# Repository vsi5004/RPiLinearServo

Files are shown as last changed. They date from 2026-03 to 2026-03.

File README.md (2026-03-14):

# RPiLinearServo

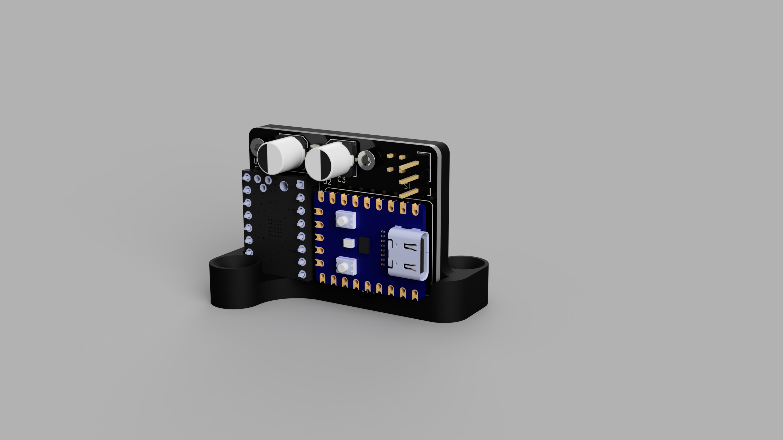
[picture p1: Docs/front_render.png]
RPiLinearServo


A closed-loop linear servo based on the RP2040, using a micro stepper linear actuator with an 8.5 mm throw and a BTT v1.3 TMC2209 driver. Designed as an RC servo replacement / turnout actuator for model railroads that allows for smooth and reliable slow speed operation and ease of configuration for a wide range of applications.

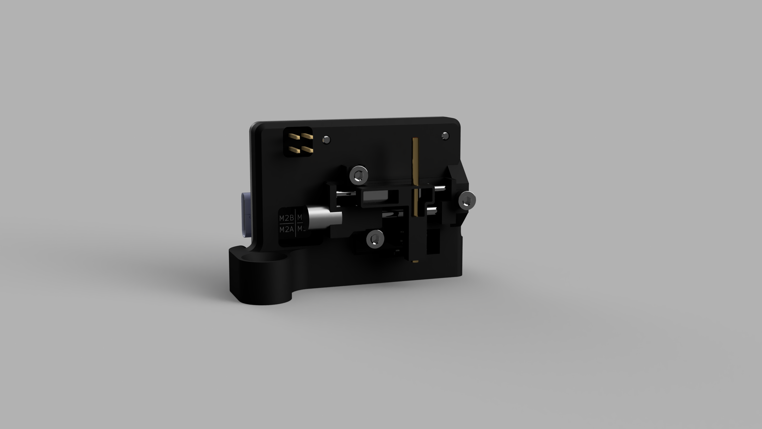
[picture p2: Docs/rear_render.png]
RPiLinearServo rear


## Features

- Controllable via standard servo PWM signal allowing for plug-and-play integration in systems designed for miniature R/C servos
- Easy firmware updates - just drag and drop compiled binary into mounted drive to flash
- Widely configurable by editing a `CONFIG.INI` file when device is connected as a usb drive to allow for adaptation to wide range of use cases
- Smooth, quiet, controllable, and repeatable motion not available in smaller servos
- Non-backdrivable lead screw linear stage can be powered off in a low power state while not in use
- Automatic homing routine runs once and is then stored and persists throughout the life of the device
- Closed loop magnetic feedback allows for seamless, accurate adjustments if external factors cause motor to miss steps
- Interactive USB CLI (via serial monitor) exposes full command set for motion control, diagnostics, and debugging

## Hardware

| Component | Details |
|---|---|
| MCU | Waveshare RP2040-Zero |
| Driver | BTT TMC2209 v1.3 SilentStepStick |
| Actuator | Micro stepper linear slide, 8.4 mm travel (~208.3 full steps/mm) |
| Hall Sensor | TI DRV5055 A2 (optional, for closed-loop verification) |

See the [PCB README](PCB/README.md) for the full schematic, BOM, and GPIO assignments.

## Getting Started

### Flash the firmware

1. Hold **BOOTSEL** on the RP2040-Zero and plug in USB.
2. Drag `RPiLinearServo.uf2` onto the **RPI-RP2** drive.
3. The board reboots and enumerates as a composite USB device (CDC serial + MSC config drive).

Pre-built `.uf2` files are available on the [Releases](../../releases) page — or build from source (see the [Firmware README](Firmware/RPiLinearServo/README.md)).

### Connect a PWM signal

Wire a standard RC servo signal (1000–2000 µs) to GP0. On the first valid pulse the servo automatically homes (drives into the hardstop, backs off, and zeroes) then begins tracking the PWM target.

If the PWM signal is lost for more than 100 ms (configurable), the motor is disabled and the LED enters an idle heartbeat.

### Configure via USB drive

The device mounts a small USB drive named **LINEARSERVO** containing `CONFIG.INI`. Edit with any text editor, save, and **safely eject**. The firmware applies changes within ~500 ms.

```ini
[stroke]
stroke_mm = 8.40
full_steps_per_mm = 208.3

[driver]
dir_invert = false
run_current_ma = 100
hold_current_ma = 50

[motion]
default_speed_mm_s = 40.0
max_accel_mm_s2 = 80.0
auto_disable_ms = 2000

[rc_pwm]
min_us = 1000
max_us = 2000

[led]
dark_mode = false

[power]
sleep_when_idle = false

[sensor]
use_hall_effect = false
```

### USB CLI

Connect a serial terminal (PuTTY, minicom, `screen /dev/ttyACM0 115200`) to the CDC port. The CLI is always active alongside PWM control.

```
> help
Commands:
  move <steps> [speed_hz]  Move relative steps (negative = reverse)
  run [speed_hz]           Continuous stepping
  stop                     Stop immediately
  home                     Run homing sequence
  enable                   Enable motor driver
  disable                  Disable motor driver
  dir <fwd|rev>            Set direction for 'run'
  speed <hz>               Set default speed
  pos                      Print position
  status                   Print full status
  pwm                      Print PWM input status
  nvm                      Print/save position state
  hall                     Hall sensor reading
  hallcal                  Dump hall calibration table
  faultclr                 Clear stall fault
  help                     This message
```

CLI commands go through the same servo loop state machine as PWM-driven moves, so LED and driver enable behaviour is always consistent.

## Project Structure

| Directory | Description | Details |
|---|---|---|
| [Firmware/RPiLinearServo](Firmware/RPiLinearServo/README.md) | RP2040 firmware (C++17, Pico SDK) | Build instructions, architecture, module reference |
| [PCB](PCB/README.md) | KiCad 8 schematic & PCB | BOM, GPIO map, sourcing notes, Gerber outputs |
| [Mechanical](Mechanical/README.md) | 3D-printable mounting hardware | Mount variants, print settings, additional parts |
| [Docs](Docs/) | Renders and specifications | Project renders, design spec |

## License

This project is licensed under the [MIT License](LICENSE).

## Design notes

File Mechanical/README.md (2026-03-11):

# Mechanical — RPiLinearServo

3D-printable mounting hardware for the RPiLinearServo assembly. Multiple base variants are included to suit different installation orientations.

## Mount Variants

| File | Description |
|---|---|
| `Base - Vertical.3mf` | Standard vertical mount — actuator perpendicular to the mounting surface |
| `Base - Vertical (Long Screws).3mf` | Vertical mount variant with taller screw bosses for longer fasteners |
| `Base - Horizontal Left.3mf` | Horizontal mount — actuator parallel to the mounting surface, offset left |
| `Actuator Horn.3mf` | Output horn that attaches to the actuator slider |

The vertical mounts are intended for under-baseboard turnout installations where the actuator pushes/pulls a wire or rod through the surface. The horizontal mount is for side-mounting applications where the actuator drives a linkage parallel to the mounting plane.

## Print Settings

These parts are designed for FDM printing with standard settings:

| Parameter | Recommended |
|---|---|
| Layer height | 0.2 mm |
| Infill | 20–30 % |
| Material | PLA or PETG |
| Supports | Not required |
| Walls / perimeters | 3–4 |
| Top / bottom layers | 4–5 |

### Orientation

- **Base variants** — print flat on the mounting face (as oriented in the 3MF files). No supports needed.
- **Actuator horn** — print flat. The connection features are designed to print cleanly without supports.

## Additional Parts and Materials

Beyond the 3D-printed parts and the PCB assembly, you will need:

| Item | Qty | Notes |
|---|---|---|
| Micro stepper linear actuator (8.4 mm throw) | 1 | The actuator the PCB is designed around |
| M2 or M2.5 screws | 2–4 | For mounting the base to your surface (length depends on variant) |
| M2 screws (short) | 2 | For securing the PCB to the base mount |
| Hookup wire | — | For PWM signal and power connections |
| JB Weld Pro Cold Weld Epoxy| - | Used for fixing actuator horn to linear slide |
| 1.5mm OD x 1.0 ID x 20mm brass tubing | 1 | Acts as a bushing for pushrod | 
| Piano wire or control rod | 1 | For turnout linkage (vertical mount applications) |

## Assembly

1. Secure the PCB to the printed base using M2 screws.
2. Connect the stepper actuator to the J2 motor header.
3. Route the PWM signal wire and power leads.
4. If using a vertical mount for turnout control, run a piano wire or control rod through the horn and the baseboard to the tie bar.
5. Mount the assembly under the baseboard with M2/M2.5 screws.

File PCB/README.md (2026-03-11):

# PCB — RPiLinearServo

KiCad schematic and PCB design files for the RPiLinearServo controller board.

## GPIO Assignments

| Signal | RP2040-Zero | TMC2209 Pin | Notes |
|---|---|---|---|
| PWM input | GP0 | — | RC servo signal via PIO1/SM1 |
| nENABLE | GP1 | EN | Active-low driver enable |
| STEP | GP2 | STEP | PIO0/SM0 driven |
| DIR | GP3 | DIR | GPIO |
| UART TX | GP4 | PDN/UART | Via 1 kΩ series resistor on PCB |
| UART RX | GP5 | PDN/UART | Loopback on bus |
| INDEX | GP7 | INDEX | Unused (reserved) |
| DIAG | GP9 | DIAG | Unused (reserved) |
| LED | GP16 | — | WS2812 RGB via PIO1/SM0 |
| Hall sensor | GP26 | — | DRV5055 A2 analog via ADC0 |

### UART bus isolation

The 1 kΩ series resistor (R1) between GP4 and the TMC2209 PDN/UART pin provides signal isolation so the driver can pull the bus low during reply frames without fighting the RP2040 TX output. GP4 is tri-stated after each write to allow the TMC2209 to respond over the half-duplex bus.

### PWM input protection

The PWM input on GP0 is routed through a 74LVC1G17 Schmitt-trigger buffer (U4) for signal conditioning. A TPD1E10B06DPYR ESD protection diode (D1) clamps the input to protect against transient voltage spikes from the RC servo signal line.

## Bill of Materials

| Ref | Part | Value / Description | Package | Qty |
|---|---|---|---|---|
| U2 | Waveshare RP2040-Zero | Dual-core RP2040 MCU module | Through-hole module | 1 |
| U1 | BTT TMC2209 v1.3 SilentStepStick | Stepper driver with UART | Through-hole module | 1 |
| U3 | TI DRV5055A2xDBZxQ1 | Ratiometric linear hall-effect sensor, 25 mV/mT | SOT-23 | 1 |
| U4 | 74LVC1G17 | Single Schmitt-trigger buffer | SOT-23-5 | 1 |
| D1 | TI TPD1E10B06DPYR | ESD protection diode, ±30 kV HBM | 0402 | 1 |
| C1, C3 | Panasonic EEEFPC101XAP | 100 µF 16 V aluminum electrolytic | Radial (custom footprint) | 2 |
| C2, C5 | Ceramic | 2.2 µF | 0805 | 2 |
| C4, C6 | Ceramic | 0.1 µF (decoupling) | 0402 | 2 |
| R1, R2 | Resistor | 1 kΩ | 0603 | 2 |
| R3 | Resistor | 330 Ω | 0603 | 1 |
| J1 | Pin header 1×3 | Hall sensor / PWM input connector | 2.54 mm pitch | 1 |
| J2 | Pin header 2×2 (omit, used for pads only)| Stepper motor phase connector | 2.54 mm pitch | 1 |

### Sourcing notes

| Part | Suggested source |
|---|---|
| Waveshare RP2040-Zero | [Waveshare](https://www.waveshare.com/rp2040-zero.htm), AliExpress, Amazon |
| BTT TMC2209 v1.3 SilentStepStick | [BIGTREETECH](https://biqu.equipment/products/bigtreetech-tmc2209-stepper-motor-driver-for-3d-printer-board-vs-tmc2208), Amazon, AliExpress |
| TI DRV5055A2xDBZxQ1 | DigiKey, Mouser, LCSC |
| 74LVC1G17 | DigiKey, Mouser, LCSC |
| TPD1E10B06DPYR | DigiKey (296-30406-1-ND), Mouser |
| Panasonic EEEFPC101XAP | DigiKey (PCE4534CT-ND), Mouser |
| Passives (0402/0603/0805) | LCSC, DigiKey, Mouser |

All SMD passives use hand-solder footprints with extended pads for easier assembly.

## Design Files

| Path | Description |
|---|---|
| `RPiLinearServo.kicad_sch` | Schematic |
| `RPiLinearServo.kicad_pcb` | PCB layout |
| `RPiLinearServo.kicad_pro` | KiCad project |
| `RPiLinearServo.step` | 3D model of assembled board |
| `Components/` | Custom KiCad symbol libraries + 3D STEP models |
| `CustomFootprints/` | Custom KiCad footprint libraries |

## Manufacturing Outputs

Pre-generated Gerber and drill files are in `Outputs/`:

| File | Description |
|---|---|
| `*-F_Cu.gbr`, `*-B_Cu.gbr` | Front/back copper |
| `*-F_Mask.gbr`, `*-B_Mask.gbr` | Front/back solder mask |
| `*-F_Paste.gbr`, `*-B_Paste.gbr` | Front/back paste stencil |
| `*-F_Silkscreen.gbr`, `*-B_Silkscreen.gbr` | Front/back silkscreen |
| `*-Edge_Cuts.gbr` | Board outline |
| `*-PTH.drl`, `*-NPTH.drl` | Plated / non-plated drill files |
| `*-top-pos.csv`, `*-bottom-pos.csv` | Pick-and-place position files |
| `*-BOM.csv` | Bill of materials (semicolon-delimited) |
| `*-job.gbrjob` | Gerber job file |

These files are ready to upload directly to PCB fabricators such as JLCPCB, PCBWay, or OSH Park.

### PCB specifications

| Parameter | Value |
|---|---|
| Minimum trace width | 0.2 mm |
| Default trace width | 0.2 mm |
| Via diameter / drill | 0.6 mm / 0.3 mm |
| Copper-to-edge clearance | 0.4 mm |
| Layers | 2 |

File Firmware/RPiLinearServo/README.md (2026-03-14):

# Firmware — RPiLinearServo

C++17 firmware for the RP2040-Zero targeting the Pico SDK. Implements closed-loop stepper control, RC PWM tracking, USB configuration, and interactive CLI.

## Build

### Prerequisites

- [Pico SDK](https://github.com/raspberrypi/pico-sdk) v2.2.0 — set `PICO_SDK_PATH` environment variable
- ARM GCC toolchain (14.2 Rel1 or compatible)
- CMake ≥ 3.13
- Ninja (or Make)

### Build from source

```bash
cd Firmware/RPiLinearServo
mkdir -p build && cd build
cmake ..
ninja
```

This produces `RPiLinearServo.uf2` along with `.bin`, `.hex`, `.dis` (disassembly), and `.map` (symbol map) outputs.

### Flash

1. Hold **BOOTSEL** on the RP2040-Zero and plug in USB.
2. Drag `RPiLinearServo.uf2` onto the **RPI-RP2** drive.
3. The board reboots and enumerates as a composite USB device (CDC serial + MSC config drive).

Alternatively, use the **Run Project** task in VS Code to build and flash in one step.

### VS Code development

The project includes CMake presets and VS Code tasks for a streamlined workflow:

1. Set `PICO_SDK_PATH` in your environment (or in `.vscode/settings.json`).
2. Open the `Firmware/RPiLinearServo` folder in VS Code.
3. CMake Tools will auto-configure the build directory.
4. Use **Build** (Ctrl+Shift+B) and **Run Project** tasks.

## Architecture

### Main loop

The firmware runs a single-core bare-metal event loop (`main.cpp`). There is no RTOS — all work is cooperative:

```
main loop
  ├── cli_poll()                  USB command processing (non-blocking)
  ├── msc_disk_poll()             Detect CONFIG.INI writes → apply settings
  ├── servo_loop_poll()           Servo state machine (see below)
  ├── status_led_update()         WS2812 LED animation state machine
  └── position_save_if_needed()   Throttled NVM write (≤ once per 30 s)
```

### Servo loop state machine (`motion/servo_loop.cpp`)

All motor control — whether initiated by PWM input or the USB CLI — flows through a single state machine.  This guarantees that the driver enable pin, LED status, and idle timeout are always consistent regardless of the command source.

```
  ┌──────┐   first valid PWM   ┌────────┐  blocking   ┌─────────┐
  │ IDLE │ ─────────────────► │ HOMING │ ──────────► │ HOLDING │
  └──┬───┘                     └────────┘             └────┬────┘
     │  move cmd / PWM error                               │
     │  ┌────────┐  move complete   ┌─────────┐            │
     └►│ MOVING │ ────────────────►│ HOLDING │◄───────────┘
       └────────┘                   └────┬────┘
                                         │ auto_disable_ms timeout
                                         │ or PWM signal lost
                                         ▼
                                      ┌──────┐
                                      │ IDLE │
                                      └──────┘
```

**States:**

| State | EN pin | LED | Description |
|---|---|---|---|
| IDLE | Disabled | Amber breathing | Motor off, waiting for input or dormant entry |
| HOMING | Enabled | Blue breathing | Blocking hardstop homing in progress |
| MOVING | Enabled | Solid blue | Stepgen actively running toward a target |
| HOLDING | Enabled | Solid green | At target, idle timer counting toward auto-disable |

Transitions are evaluated once per poll in a single `switch` block.  The `enter_state()` helper is the **only** place that touches the EN pin or LED status, eliminating any possibility of EN/LED desynchronisation.

**Public API** (used by both CLI and PWM tracking):

| Function | Description |
|---|---|
| `servo_loop_move(steps, speed, accel)` | Start an accelerated finite move |
| `servo_loop_run(speed)` | Start continuous stepping |
| `servo_loop_stop()` | Stop and enter HOLDING |
| `servo_loop_enable()` | Enable driver (IDLE → HOLDING) |
| `servo_loop_disable()` | Disable driver (any → IDLE) |
| `servo_loop_home()` | Run blocking homing sequence |

### Interrupt / real-time layer

| Source | Handler | Purpose |
|---|---|---|
| PIO0 IRQ0 | Step counter ISR | Increment/decrement position on every STEP rising edge |
| 1 kHz repeating timer | Accel/decel ISR | Update PIO clock divider for trapezoidal speed profile |
| PIO1 RX FIFO | PWM capture | New pulse width measurement available |

## Modules

### Step Generation (`drivers/stepgen/`)

PIO0/SM0 runs a 4-cycle program that generates a square wave on the STEP pin and fires IRQ0 on each rising edge. The CPU IRQ handler maintains an exact position counter (no drift).

Speed is controlled by adjusting the PIO state machine clock divider:

$$f_{step} = \frac{f_{clk\_sys}}{4 \times clk\_div}$$

Key functions:
- `stepgen_move(steps, speed_hz)` — move exactly N steps at constant speed
- `stepgen_move_accel(steps, max_hz, accel_hz_per_s)` — trapezoidal acceleration profile via 1 kHz timer
- `stepgen_run(speed_hz)` — continuous stepping
- `stepgen_get_position()` — read current step count

### TMC2209 Driver (`drivers/tmc2209/`)

Communicates over hardware UART1 (115200 baud, 8N1) on a half-duplex single-wire bus. Reads and writes TMC2209 registers with CRC8 validation. The TX pin is tri-stated after each write to allow the driver to reply.

At startup the firmware writes the following registers:

| Parameter | Default | Description |
|---|---|---|
| `run_current_ma` | 100 | RMS run current (mA) |
| `hold_current_ma` | 50 | RMS hold current (mA) |
| `microsteps` | 8 | Microstepping divisor |
| `stealthchop_en` | true | StealthChop (quiet) mode |
| `tpowerdown` | 46 | ~1 s IRUN → IHOLD ramp |

- `GCONF = 0x1C0` — full software current control, PDN disabled, register-select microstepping, multistep filter.
- `CHOPCONF` — only MRES and interpolation bits are modified; OTP defaults for TBL / HSTRT / HEND are preserved.

All parameters are runtime-configurable via the USB config drive (`CONFIG.INI`).

### PWM Input (`drivers/pwm_input/`)

PIO1/SM1 measures the HIGH time of an RC servo pulse at 16 ns resolution (125 MHz system clock). Valid range is configurable (default 1000–2000 µs). A timeout fires if no valid pulse is received within `pwm_timeout_ms`.

### Hall Sensor (`drivers/hall_sensor/`)

Reads the DRV5055 analog output on ADC0 (GP26) with 64× oversampling across 5 accumulated reads per update. An optional EMA filter smooths the signal. Used for:
- Stall detection during homing (voltage derivative monitoring)
- Post-move position verification via 128-entry calibration LUT
- Lost-step correction (single attempt, then fault if still out of tolerance)

### Dormant Sleep (`power/dormant.cpp`)

When `sleep_when_idle` is enabled and the PWM signal is lost, the RP2040 enters XOSC dormant mode — halting the crystal oscillator and both PLLs for minimal power draw. The device wakes instantly on the next PWM rising edge (GP0).

Entry conditions (all must be true):
- `sleep_when_idle = true` in config
- PWM signal timed out and motor auto-disabled **or** no valid pulse received within 5 seconds of boot
- USB host not mounted (prevents sleeping while CLI / config drive is in use)

Pre-sleep sequence: force an unconditional position save to flash, stash position in RAM, disable motor and LED, disable all PIO state machines, clear PIO instruction memory, switch clocks to XOSC, shut down both PLLs.

Post-wake sequence: restore PLLs and system clock, re-initialise all peripherals (USB, TMC2209, PIO drivers, hall sensor), restore position from RAM (avoids stale-flash mismatches), re-init the servo loop.

### Servo Loop (`motion/`)

The top-level motion coordinator.  An explicit state machine (IDLE → HOMING → MOVING → HOLDING) polled from the main loop.  All motor commands — from both the USB CLI and PWM tracking — flow through the same `servo_loop_*` API, ensuring EN pin, LED, and timeout state are always consistent.

Key behaviours:
- **PWM tracking** — maps pulse width to a target position, applies deadband, and commands moves with acceleration
- **Auto-home** — triggers homing on the first valid PWM pulse if not already homed
- **Post-move verification** — after each move settles, compares the hall sensor reading against the calibration LUT and attempts a single correction if a mismatch is detected
- **Auto-disable** — disables the driver after `auto_disable_ms` of idle time (HOLDING → IDLE)
- **PWM signal loss** — if the PWM signal drops during a move, the servo transitions directly from MOVING to IDLE on completion rather than lingering in HOLDING

### Homing (`motion/homing.cpp`)

Hardstop homing sequence:

1. Drive `home_margin × stroke` steps into the end-stop at `home_speed_mm_s`
2. Monitor hall sensor: stall detected when voltage derivative falls below threshold for 5 consecutive samples (after 20% of stroke has been commanded)
3. Back off by `backoff_mm` with acceleration
4. Calibration sweep: slow pass across full stroke to build 128-entry V-curve LUT
5. Reset position to 0, save LUT to flash

### USB (`usb/`)

Composite TinyUSB device with two interfaces:

- **CDC** — USB serial port for the interactive CLI
- **MSC** — virtual FAT12 mass storage drive (8 KB RAMdisk) exposing `CONFIG.INI`

The MSC driver detects write completions with a 500 ms idle timeout, then parses the INI, validates ranges, saves to flash, and re-applies driver settings.

### Storage (`storage/`)

All persistent data lives in dedicated 4 KB sectors at the end of the 2 MB flash:

| Offset | Purpose | Protection |
|---|---|---|
| `0x1F0000` | Position slot A | CRC32, dual-slot wear leveling |
| `0x1F1000` | Position slot B | CRC32, dual-slot wear leveling |
| `0x1F2000` | ServoConfig | CRC32, magic + version |
| `0x1F3000` | Hall calibration LUT | CRC32, magic + version |

Position saves are throttled to once every 30 seconds to protect flash endurance. An immediate save occurs after homing.

### Status LED (`ui/status_led.cpp`)

WS2812 state machine with the following visual states:

| State | Pattern |
|---|---|
| OFF | Dark (dark mode enabled) |
| IDLE | Amber breathing pulse (~5 s period) |
| HOLDING | Solid green |
| MOVING | Solid blue |
| HOMING | Breathing blue (500 ms cycle) |
| HOMING_DONE | 3× green flash → HOLDING |
| STALL_FAULT | Rapid red flash |
| ERROR | Solid red |

## Configuration Reference

The `ServoConfig` struct (`include/config.h`) contains all runtime parameters. Defaults are compiled in and can be overridden via the USB config drive or flash persistence.

| Section | Parameter | Default | Description |
|---|---|---|---|
| Stroke | `stroke_mm` | 8.40 | Actuator travel (mm) |
| | `full_steps_per_mm` | 208.3 | Motor full steps per mm |
| Driver | `dir_invert` | false | Invert direction pin |
| | `run_current_ma` | 100 | RMS run current (mA) |
| | `hold_current_ma` | 50 | RMS hold current (mA) |
| | `microsteps` | 8 | Microstepping divisor |
| | `stealthchop_en` | true | StealthChop mode |
| Motion | `default_speed_mm_s` | 40.0 | Default move speed (mm/s) |
| | `max_accel_mm_s2` | 80.0 | Acceleration limit (mm/s²) |
| | `auto_disable_ms` | 2000 | Idle timeout before disabling driver (0 = never) |
| RC PWM | `pwm_min_us` | 1000 | Minimum valid pulse width (µs) |
| | `pwm_max_us` | 2000 | Maximum valid pulse width (µs) |
| | `pwm_timeout_ms` | 100 | Signal-lost timeout (ms) |
| LED | `dark_mode` | false | Disable status LED |
| Power | `sleep_when_idle` | false | Enter dormant mode when PWM signal is lost (wake on next pulse) |
| Sensor | `use_hall_effect` | false | Enable hall sensor feedback |

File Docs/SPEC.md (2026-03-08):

# SPEC.md  
RP2040 Linear Servo Firmware Specification  
Target Board: Waveshare RP2040-Zero  

---

## 0. Overview

This firmware implements a closed-loop "linear servo" using an RP2040 and a linear stepper actuator. The device behaves like an RC servo replacement and optionally a turnout actuator.

Features:

- RC PWM input (standard servo pulse)
- Closed-loop position control using linear Hall sensor
- Automatic homing against mechanical stop
- USB Mass Storage (MSC) runtime configuration drive
- INI-based configuration file (`CONFIG.INI`)
- Persistent position and calibration storage in flash
- UF2 firmware update via BOOTSEL
- Optional USB CDC logging

Primary development stack: Pico SDK (C/C++) + TinyUSB.

---

## 1. Hardware Assumptions

### 1.1 MCU
- RP2040
- 2MB external QSPI flash
- USB device mode

### 1.2 Motor Driver

TMC2209 SilentStepStick

Interface:
- STEP / DIR / EN (STEP/DIR class — same as DRV8825)
- Single-wire UART for startup configuration (current, microstepping, StealthChop, StallGuard)
- DIAG output for StallGuard2 stall detection

GPIO assignments (Waveshare RP2040-Zero):

| Signal | GPIO | Direction | Notes |
|---|---|---|---|
| nENABLE | GP1 | OUT | Active-low |
| STEP | GP2 | OUT | PIO state machine (PIO0) |
| DIR | GP3 | OUT | GPIO |
| UART TX | GP4 | OUT | To TMC2209 PDN/UART via 1K R1 on PCB; also UART1_TX |
| UART RX | GP5 | IN | Loopback on same UART bus; also UART1_RX |
| DIAG | GP7 | IN | StallGuard2 output (high = stall detected) |
| INDEX | GP9 | IN | TMC2209 step pulse output (future use) |
| PWM input | GP0 | IN | RC servo signal |
| Hall sensor | GP26 | IN | Analog (ADC0) |

The UART is implemented with hardware UART1 (GP4=UART1_TX, GP5=UART1_RX) at 115200 baud 8N1. This leaves both PIO0 and PIO1 available for step generation, PWM capture and other future use.

### 1.3 Sensors
- Linear analog Hall sensor (e.g., A1302)
- Analog speed potentiometer
- RC PWM input

### 1.4 Mechanical
- Linear stepper actuator
- Non-backdrivable
- Hard end stop safe for stall homing

---

## 2. Functional Requirements

### 2.1 PWM Input

Standard RC servo PWM:
- 50Hz nominal
- 1000–2000 microseconds typical

Mapping:

```
pos_mm = (pulse_us - min_us) * stroke_mm / (max_us - min_us)
```

Clamped to [0, stroke_mm].

Configuration parameters:
- `min_us`
- `max_us`
- `timeout_ms`
- `pwm_zero_disables`
- `valid_margin_us`

Behavior:
- If no valid pulse for `timeout_ms`, PWM considered absent.
- If `pwm_zero_disables=true`, disable motor driver.
- Resume when valid PWM returns.
- If not homed and valid PWM appears → run homing first.

PWM capture must use PIO for deterministic measurement.

---

### 2.2 Homing

Triggered if:
- `homed=false`
- valid PWM received

Two homing modes (selected by `use_stallguard` config flag):

#### StallGuard homing (preferred, `use_stallguard = true`)

1. Configure TMC2209 StallGuard threshold via UART (`SGTHRS` register).
2. Move toward home direction at `home_speed_mm_s`.
3. Poll DIAG pin (GP7). When TMC2209 detects stall, DIAG goes high.
4. Call `stepgen_stop()` immediately — motor stops at contact point.
5. Back off by `backoff_mm`.
6. Set logical zero position.
7. Persist `homed=true`.

StallGuard is only active when the step rate exceeds `TCOOLTHRS` (set to maximum in firmware). Threshold tuning: increase `sg_threshold` if false triggers during normal motion; decrease if stall is not detected.

#### Time-based homing (fallback, `use_stallguard = false`)

1. Move toward home direction at `home_speed_mm_s`.
2. Drive 120% of stroke — motor stalls but PIO continues generating pulses.
3. Wait for step count to exhaust (all pulses issued).
4. Back off by `backoff_mm`.
5. Set logical zero position.

#### Hall latch (future)

When `use_latch = true`:
- After initial stall stop, approach slowly at `latch_speed_mm_s`
- Use Hall sensor position as zero reference

---

### 2.3 Closed Loop Control

Control loop frequency: 200–1000 Hz.

Inputs:
- Target position (from PWM)
- Current position (from Hall sensor)

Motion limits:
- `max_speed_mm_s`
- `min_speed_mm_s`
- `max_accel_mm_s2`
- `deadband_mm`

Speed potentiometer scales max speed:

```
effective_max_speed = min_speed + pot_norm * (max_speed - min_speed)
```

Stop stepping when error < deadband.

---

### 2.4 Disable Behavior

If PWM absent and `pwm_zero_disables=true`:
- Disable driver (EN pin)
- Stop control loop motion
- Assume position holds (non-backdrivable)

Persist position with throttling.

---

### 2.5 Boot Position Recovery

On boot:
- Load `homed` and `last_position_mm`
- Read Hall sensor

If mismatch > `pos_mismatch_mm`, trust Hall reading.

If not homed:
- Require homing before motion.

---

### 2.6 Nonvolatile Storage

Persist:
- `homed`
- `last_position_mm`
- Last-good config checksum
- Calibration data

Flash requirements:
- CRC protected
- Versioned struct
- A/B slot or ring buffer

Write throttling:
- Save only when disabled OR
- Every `pos_save_interval_s`
- Never more often than `min_save_interval_s`

---

## 3. USB Mass Storage Configuration Drive

### 3.1 USB Classes

- Required: MSC
- Recommended: MSC + CDC composite

### 3.2 Volume Layout

Volume label: `LINEARSERVO`

Files:
- `CONFIG.INI` (R/W)
- `STATUS.TXT` (RO)
- `README.TXT` (optional)

Disk size: 128–256 KB FAT volume
Backed by reserved flash region.

---

### 3.3 Config Apply Logic

On MSC write:
- Track if CONFIG.INI sectors modified.
- After `config_apply_idle_ms` (e.g. 500ms no writes):
  - Parse CONFIG.INI
  - If valid:
    - Apply
    - Persist as last-good
  - If invalid:
    - Reject
    - Write error to STATUS.TXT

---

## 4. CONFIG.INI Schema

Example:

```
[meta]
version = 1

[rc_pwm]
min_us = 1000
max_us = 2000
timeout_ms = 100
pwm_zero_disables = true
valid_margin_us = 50

[stroke]
length_mm = 12.0
invert = false
deadband_mm = 0.03
pos_mismatch_mm = 0.5

[motion]
max_speed_mm_s = 6.0
min_speed_mm_s = 0.2
max_accel_mm_s2 = 30.0
idle_disable_ms = 0

[homing]
enable = true
direction = negative
home_speed_mm_s = 1.0
latch_speed_mm_s = 0.3
use_latch = true
backoff_mm = 0.3
stall_eps_mm = 0.02
stall_time_ms = 100
zero_offset_mm = 0.0

[driver]
type = tmc2209
step_pin = GP2
dir_pin = GP3
en_pin = GP1
en_active_low = true
steps_per_mm = 200.0
dir_invert = false
run_current_ma = 800
hold_current_ma = 200
microsteps = 16
stealthchop_en = true
sg_threshold = 100
use_stallguard = true

[adc]
hall_adc = ADC0
pot_adc = ADC1
adc_filter_alpha = 0.1

[sense_hall]
mode = lut
mid_adc = 2048
lut_points = 13
lut = 1980,1990,2005,2020,...

[nvm]
pos_save_interval_s = 15
min_save_interval_s = 5
```

Unknown keys must be ignored.

---

## 5. Timing

### 5.1 PWM Capture
Use PIO state machine.
Measure high time in microseconds.
Provide timeout detection.

### 5.2 Step Generation
Generate STEP pulses meeting driver timing.
Prefer PIO or high-priority timer.
Minimum pulse width configurable.

TMC2209 STEP minimum high time: 100 ns.
At `STEPGEN_MIN_CLKDIV = 8.0` and 125 MHz: high time = 128 ns (meets spec with margin).

---

### 5.3 TMC2209 UART Protocol

Single-wire half-duplex UART, 115200 baud 8N1.
PCB: GP4 (TX) → 1K R1 → bus; GP5 (RX) direct on bus.
Implemented with hardware UART1 (GP4=UART1_TX, GP5=UART1_RX).

**Write datagram (8 bytes, master → TMC2209):**

| Byte | Value | Description |
|---|---|---|
| 0 | 0x05 | Sync nibble |
| 1 | 0x00 | Slave address (MS1=0, MS2=0) |
| 2 | reg \| 0x80 | Register address with write bit |
| 3–6 | data[31:0] | 32-bit data, MSByte first |
| 7 | CRC8 | CRC of bytes 0–6 |

**Read access (master sends 4 bytes, receives 8-byte reply):**

Master send: `[0x05, 0x00, reg, CRC8(3 bytes)]`

TMC2209 reply: `[0x05, 0xFF, reg, data[31:24..7:0], CRC8]`

Note: TX bytes echo back on RX bus. Firmware drains echo bytes before reading reply.

CRC: polynomial 0x07, initial value 0x00, LSB first shift.

**Registers written at startup:**

| Register | Address | Purpose |
|---|---|---|
| GCONF | 0x00 | pdn_disable=1 (required for UART), StealthChop/SpreadCycle |
| IHOLD_IRUN | 0x10 | Run and hold current (CS values 0–31) |
| TPWMTHRS | 0x13 | StealthChop upper speed threshold (0 = always active) |
| TCOOLTHRS | 0x14 | StallGuard lower speed threshold (0xFFFFF = always active) |
| CHOPCONF | 0x6C | Microstepping resolution (MRES field bits 27:24) |
| SGTHRS | 0x40 | StallGuard2 threshold (0–255) |

### 5.4 ADC
- IIR filter:

```
filtered = filtered + alpha * (raw - filtered)
```

Alpha from config.

---

## 6. Fault Handling

Faults:
- Hall out-of-range
- Config invalid
- Position beyond stroke limits

On fault:
- Disable driver
- Set error state
- Indicate via LED and STATUS.TXT

---

## 7. Flash Layout (2MB)

Example:

- 0x000000 – firmware
- mid region – reserved
- upper 128–256 KB – MSC disk
- final 32–64 KB – NVM storage

Flash sectors aligned to 4KB boundaries.

---

## 8. Firmware Structure

Modules:

- main.cpp
- config_ini.cpp
- usb_msc_disk.cpp
- pwm_capture_pio.cpp
- drivers/stepgen/stepgen.cpp     (PIO step generator, PIO0)
- drivers/tmc2209/tmc2209.cpp     (TMC2209 register driver, hardware UART1)
- motion/homing.cpp               (StallGuard and time-based homing)
- hall_sense.cpp
- nvm_store.cpp
- control.cpp

Produce:
- .elf
- .uf2

---

## 9. State Machine

States:

- BOOT
- WAIT_PWM
- HOMING
- RUN
- DISABLED
- ERROR

Transitions:
- PWM valid → RUN or HOMING
- PWM timeout → DISABLED
- Fault → ERROR

---

## 10. Priorities

1. Robustness over complexity
2. Safe flash handling
3. Clean separation of modules
4. Fail-safe motor disable on error
5. Minimal dependencies

---

End of SPEC.md

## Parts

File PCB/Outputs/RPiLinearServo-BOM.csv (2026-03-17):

Id | Designator | Footprint | Quantity | Designation | Supplier and ref
1 | C1,C3 | CAP_EEEFPC101XAP | 2 | EEEFPC101XAP
2 | J1 | PinHeader_1x03_P2.54mm_Vertical | 1 | Conn_01x03_Pin
3 | U2 | MODULE_RP2040-ZERO | 1 | RP2040-ZERO
4 | R1,R2 | R_0603_1608Metric_Pad0.98x0.95mm_HandSolder | 2 | 1K
5 | U1 | MODULE_TMC2209_SILENTSTEPSTICK | 1 | TMC2209_SILENTSTEPSTICK
6 | C2,C5 | C_0805_2012Metric_Pad1.18x1.45mm_HandSolder | 2 | 2.2uF
7 | J2 | PinHeader_2x02_P2.54mm_Vertical | 1 | Conn_02x02_Odd_Even
8 | D1 | D_0402_1005Metric_Pad0.77x0.64mm_HandSolder | 1 | TPD1E10B06DPYR
9 | C4,C6 | C_0402_1005Metric_Pad0.74x0.62mm_HandSolder | 2 | 0.1uF
10 | U4 | SOT-23-5_HandSoldering | 1 | 74LVC1G17
11 | U3 | SOT-23_Handsoldering | 1 | DRV5055A3xDBZxQ1
12 | R3 | R_0603_1608Metric_Pad0.98x0.95mm_HandSolder | 1 | 330

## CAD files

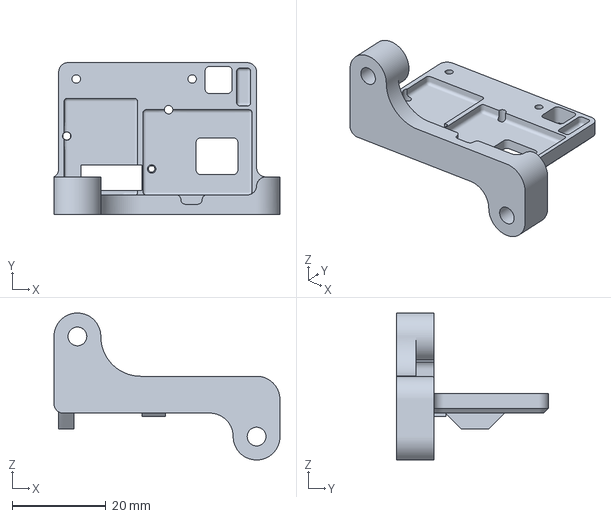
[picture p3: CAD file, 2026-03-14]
Mechanical/Base - Horizontal Left.3mf
48.2 x 32.4 x 31.4 mm

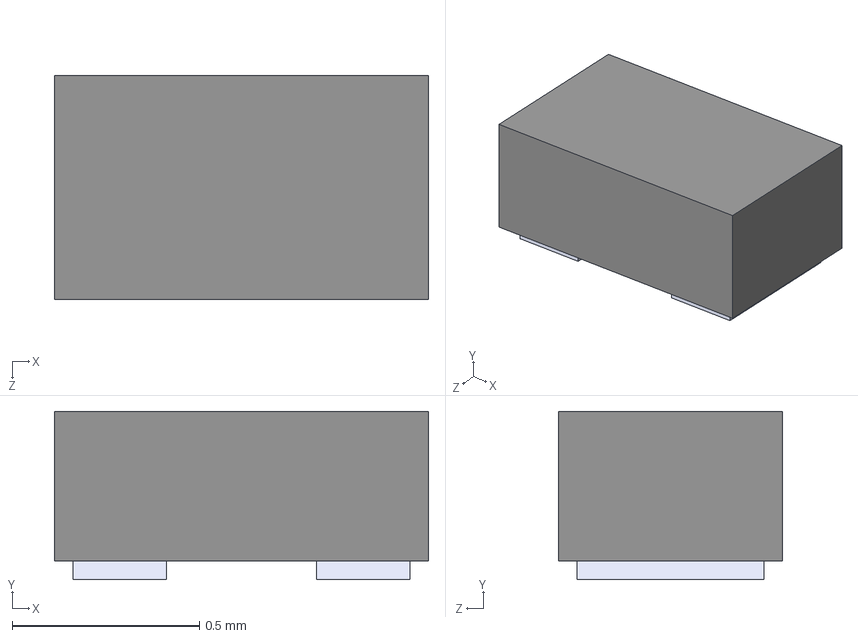
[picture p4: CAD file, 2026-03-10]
PCB/Components/TPD1E10B06DPYR.step
1.00 x 0.45 x 0.6 mm

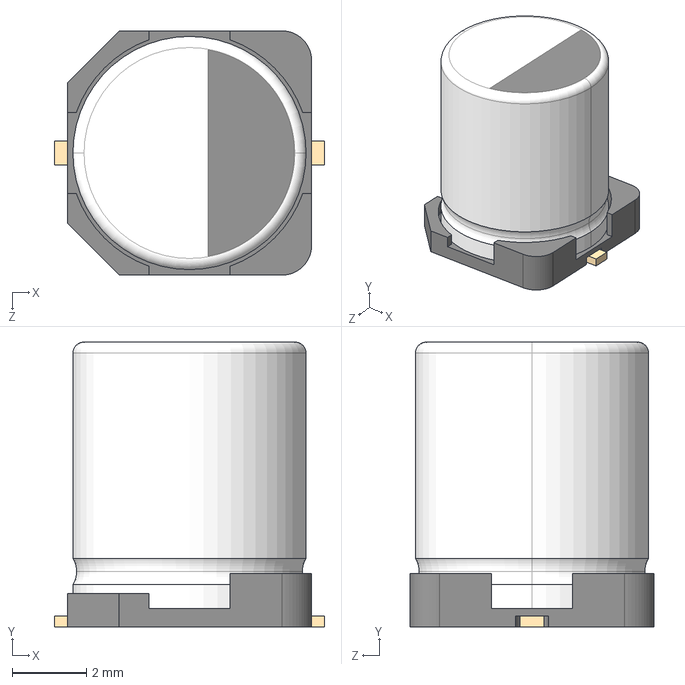
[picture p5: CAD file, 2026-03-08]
PCB/Components/EEEFPC101XAP.step
7.30 x 7.70 x 6.60 mm

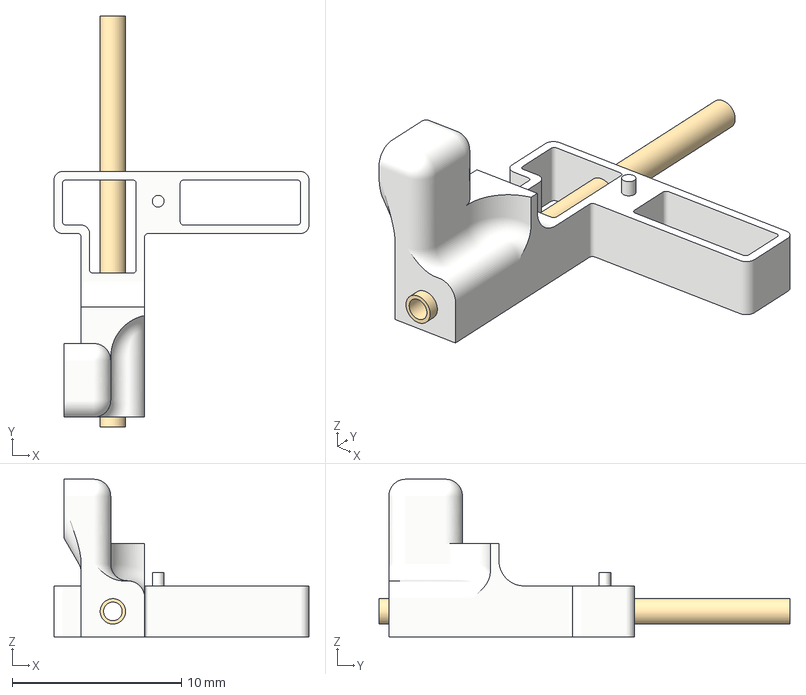
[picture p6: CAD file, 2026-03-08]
Mechanical/Actuator Horn.3mf
15.0 x 24.2 x 9.30 mm

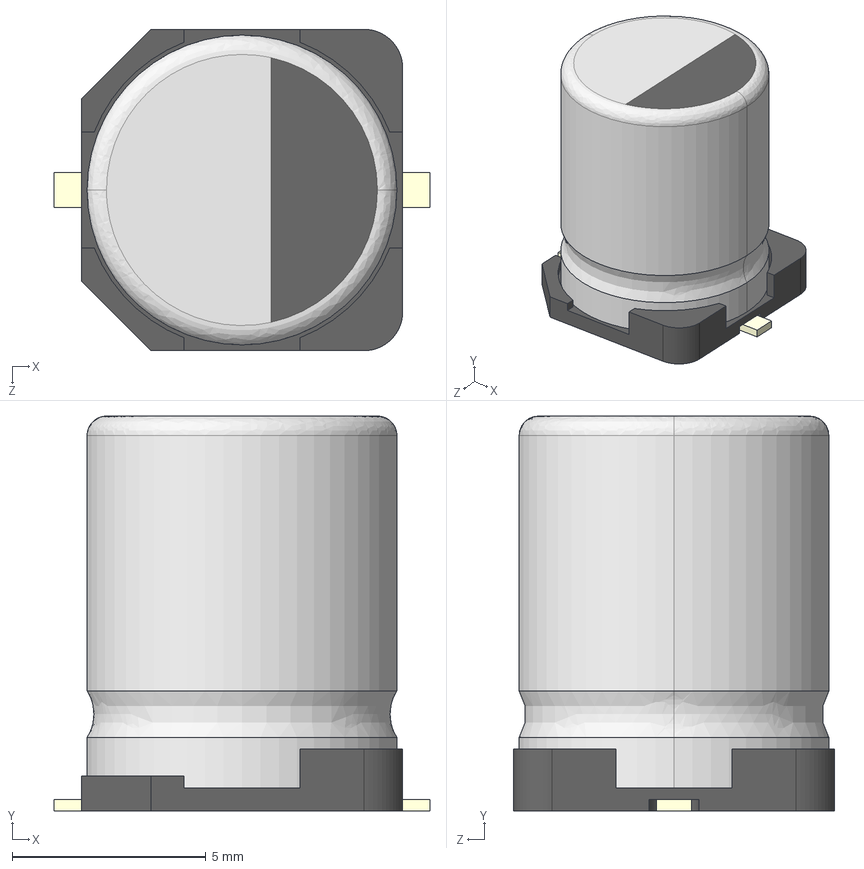
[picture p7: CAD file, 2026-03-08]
PCB/Components/EEEFP1C471AP.step
9.70 x 10.2 x 8.30 mm

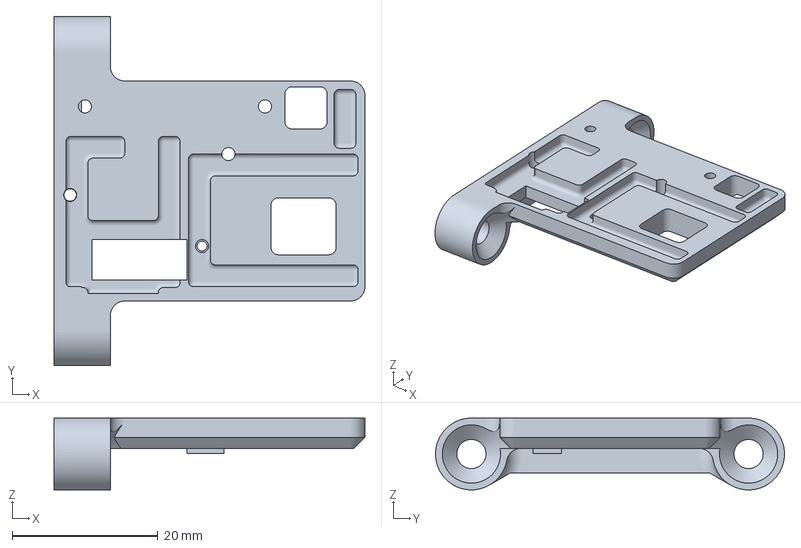
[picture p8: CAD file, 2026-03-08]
Mechanical/Base - Vertical.3mf
42.8 x 48.0 x 9.87 mm

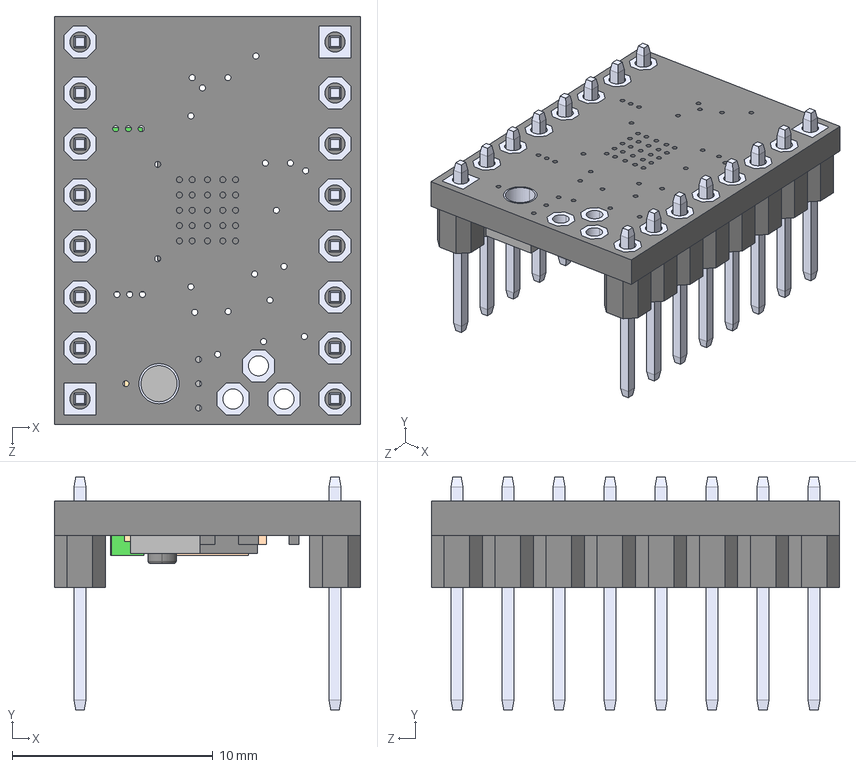
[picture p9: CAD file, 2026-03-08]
PCB/Components/TMC2209_SILENTSTEPSTICK.step
15.2 x 11.6 x 20.3 mm

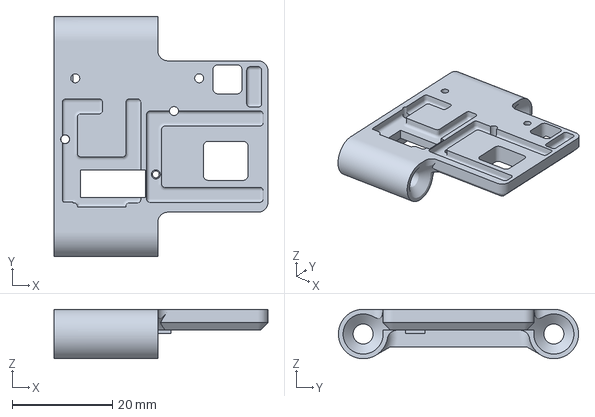
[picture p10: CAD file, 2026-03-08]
Mechanical/Base - Vertical (Long Screws).3mf
42.8 x 48.0 x 9.87 mm

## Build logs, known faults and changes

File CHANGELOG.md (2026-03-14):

# Changelog

All notable changes to this project will be documented in this file.

The format is based on [Keep a Changelog](https://keepachangelog.com/en/1.1.0/),
and this project adheres to [Semantic Versioning](https://semver.org/spec/v2.0.0.html).

## [v1.1.0] - 2026-03-14

### Changed
- Servo loop rewritten as an explicit state machine (IDLE / HOMING / MOVING /
  HOLDING) with a single `enter_state()` function controlling the EN pin and
  LED — eliminates all EN/LED desynchronisation bugs
- CLI commands (`move`, `run`, `stop`, `home`, `enable`, `disable`, `faultclr`)
  now go through the `servo_loop_*()` API instead of directly manipulating
  GPIO and LED state, ensuring consistent behaviour with PWM-driven moves
- When the PWM signal drops during a long move, the servo transitions directly
  from MOVING to IDLE on completion instead of lingering in HOLDING
- PWM valid margin widened from 50 µs to 150 µs so signals slightly outside
  the 1000–2000 µs window are accepted
- Stepper driver is no longer disabled mid-move when PWM times out; the
  `pwm_zero_disables` timeout now waits until the move finishes

### Removed
- `ramp` CLI command (superseded by the built-in trapezoidal acceleration
  profiler in `stepgen_move_accel`)

## [v1.0.0] - 2026-03-11

### Added
- PIO-based step pulse generation on PIO0/SM0 with IRQ-counted position
  tracking (no drift) and trapezoidal acceleration via 1 kHz timer
- TMC2209 stepper driver control over half-duplex UART1 with CRC8 validation,
  configurable run/hold current, microstepping, and StealthChop/SpreadCycle
- RC PWM input capture on PIO1/SM1 with 16 ns resolution (1000–2000 µs
  default range), configurable timeout, and deadband
- Servo loop: PWM-to-position tracking with auto-home on first valid pulse,
  post-move hall verification, and idle auto-disable
- Hardstop homing with hall-effect stall detection, configurable backoff, and
  128-entry V-curve calibration sweep
- Hall-effect sensor feedback (DRV5055) with 64× oversampled ADC, EMA filter,
  and lost-step detection/correction
- Composite USB device: CDC serial port (interactive CLI) + MSC virtual FAT12
  drive exposing editable `CONFIG.INI`
- Full interactive CLI with motion commands, diagnostics, and status reporting
- NVM persistence for position (dual-slot wear-leveled), configuration, and
  hall calibration LUT — all CRC32-protected in dedicated flash sectors
- WS2812 status LED with state-driven animations (idle breathing, holding,
  moving, homing, stall fault, error) and optional dark mode
- Dormant sleep mode: optional ultra-low-power XOSC dormant when PWM signal is
  lost and USB is not mounted, instant wake on next PWM rising edge
- Tag-based GitHub Actions CI/CD with automatic GitHub Releases, SHA256
  checksums, and flash instructions
- Git-tag-driven firmware versioning injected at build time via CMake
- 3D-printable mounting hardware: horizontal, vertical, and long-screw base
  variants plus actuator horn
- KiCad 8 PCB design with full BOM, Gerber outputs, and sourcing notes

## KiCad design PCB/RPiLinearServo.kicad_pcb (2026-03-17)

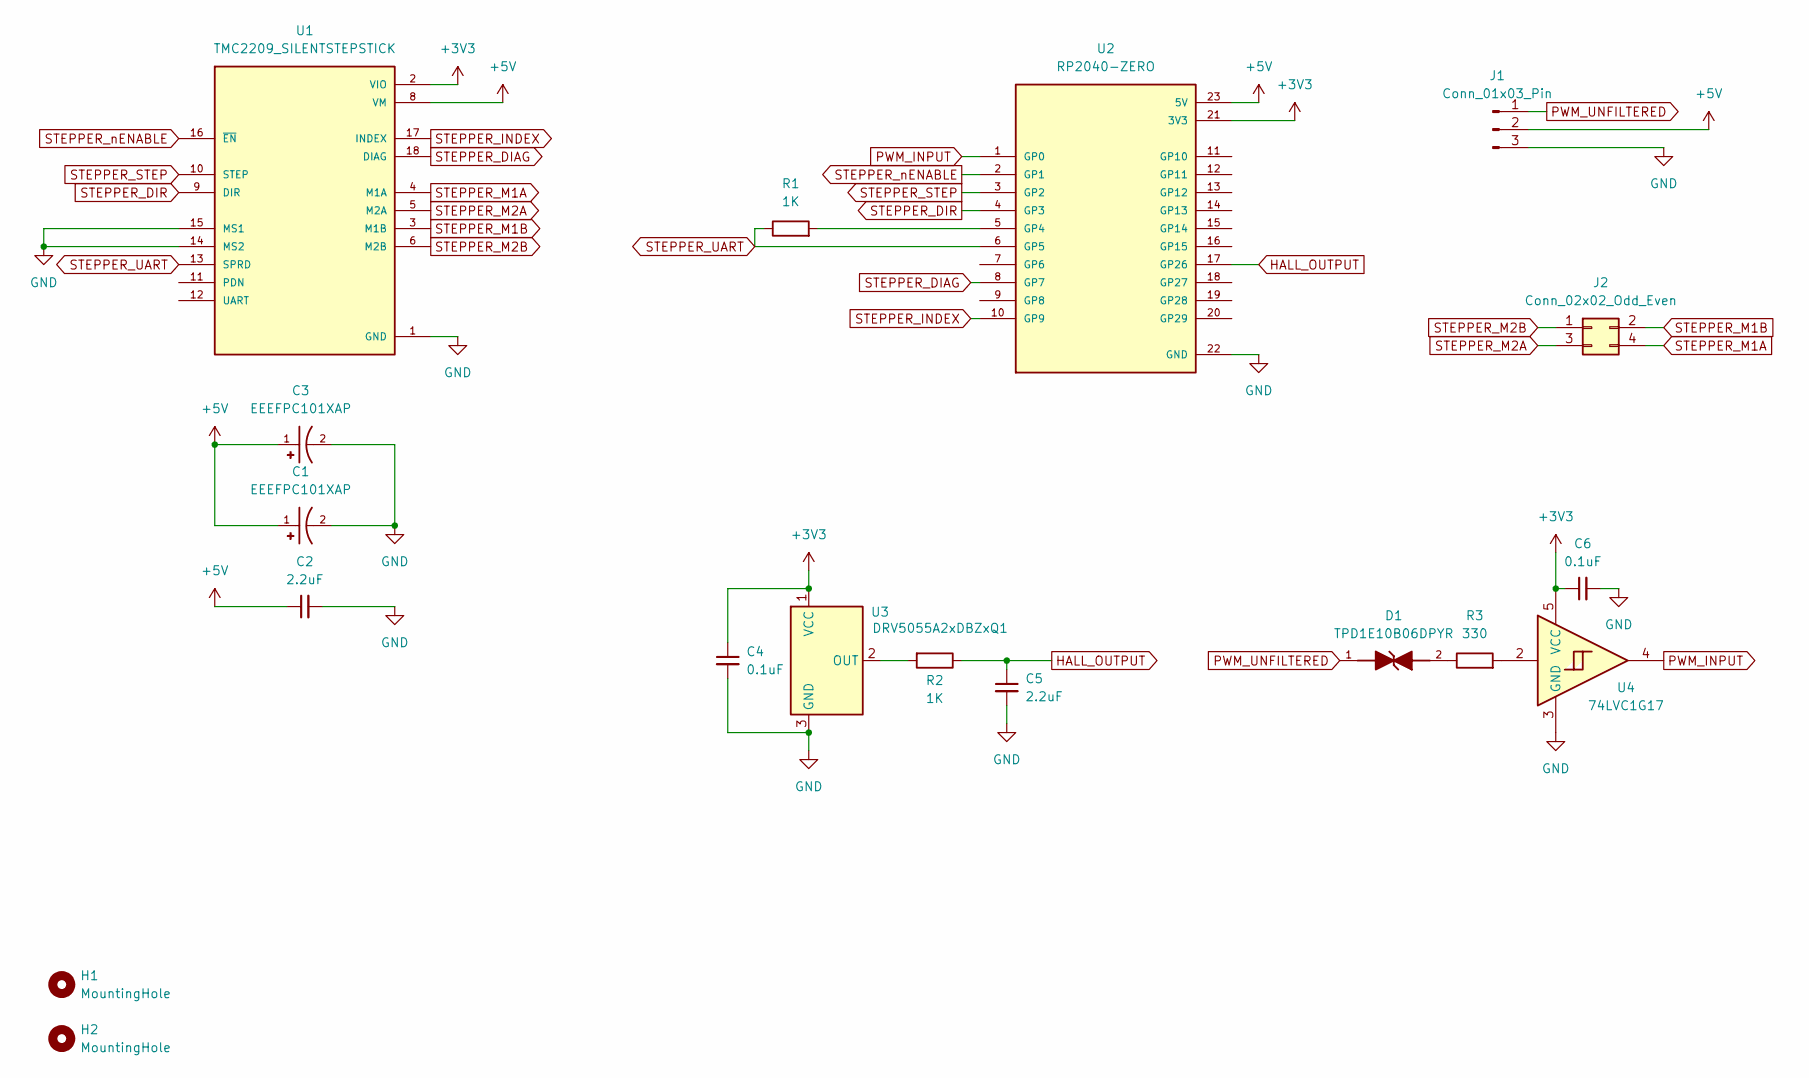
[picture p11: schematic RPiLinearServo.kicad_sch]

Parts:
C1, C3: EEEFPC101XAP; CAP_EEEFPC101XAP; PARTREV 10-Oct-19; DigiKey_Part_Number PCE4534CT-ND
C2, C5: 2.2uF; C_0805_2012Metric_Pad1.18x1.45mm_HandSolder
C4, C6: 0.1uF; C_0402_1005Metric_Pad0.74x0.62mm_HandSolder
D1: TPD1E10B06DPYR; D_0402_1005Metric_Pad0.77x0.64mm_HandSolder; PARTREV G; DigiKey_Part_Number 296-30406-1-ND
H1, H2: MountingHole; MountingHole_2.2mm_M2_DIN965_Pad
J1: Conn_01x03_Pin; PinHeader_1x03_P2.54mm_Vertical
J2: Conn_02x02_Odd_Even; PinHeader_2x02_P2.54mm_Vertical
R1, R2: 1K; R_0603_1608Metric_Pad0.98x0.95mm_HandSolder
R3: 330; R_0603_1608Metric_Pad0.98x0.95mm_HandSolder
U1: TMC2209_SILENTSTEPSTICK; MODULE_TMC2209_SILENTSTEPSTICK
U2: RP2040-ZERO; MODULE_RP2040-ZERO; PARTREV NA
U3: DRV5055A2xDBZxQ1; SOT-23_Handsoldering
U4: 74LVC1G17; SOT-23-5_HandSoldering

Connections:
+3V3: C4.1, C6.1, U1.2 (VIO), U2.21 (3V3), U3.1 (VCC), U4.5 (VCC)
+5V: C1.1, C2.1, C3.1, J1.2, U1.8 (VM), U2.23 (5V)
GND: C1.2, C2.2, C3.2, C4.2, C5.2, C6.2, J1.3, U1.1 (GND), U1.7 (GND), U1.14 (MS2), U1.15 (MS1), U2.22 (GND), U3.3 (GND), U4.3 (GND)
HALL_OUTPUT: C5.1, R2.1, U2.17 (GP26)
unnamed: D1.2, R3.1
unnamed: R3.2, U4.2
unnamed: R1.2, U2.5 (GP4)
unnamed: R2.2, U3.2 (OUT)
PWM_INPUT: U2.1 (GP0), U4.4
PWM_UNFILTERED: D1.1, J1.1
STEPPER_DIAG: U1.18 (DIAG), U2.8 (GP7)
STEPPER_DIR: U1.9 (DIR), U2.4 (GP3)
STEPPER_INDEX: U1.17 (INDEX), U2.10 (GP9)
STEPPER_M1A: J2.4, U1.4 (M1A)
STEPPER_M1B: J2.2, U1.3 (M1B)
STEPPER_M2A: J2.3, U1.5 (M2A)
STEPPER_M2B: J2.1, U1.6 (M2B)
STEPPER_STEP: U1.10 (STEP), U2.3 (GP2)
STEPPER_UART: R1.1, U1.13 (SPRD), U2.6 (GP5)
STEPPER_nENABLE: U1.16 (~EN), U2.2 (GP1)

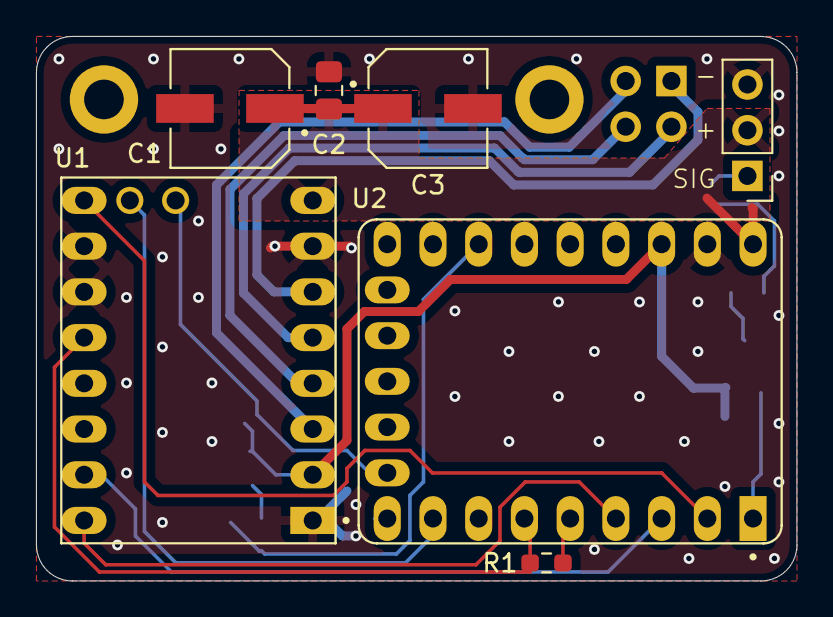
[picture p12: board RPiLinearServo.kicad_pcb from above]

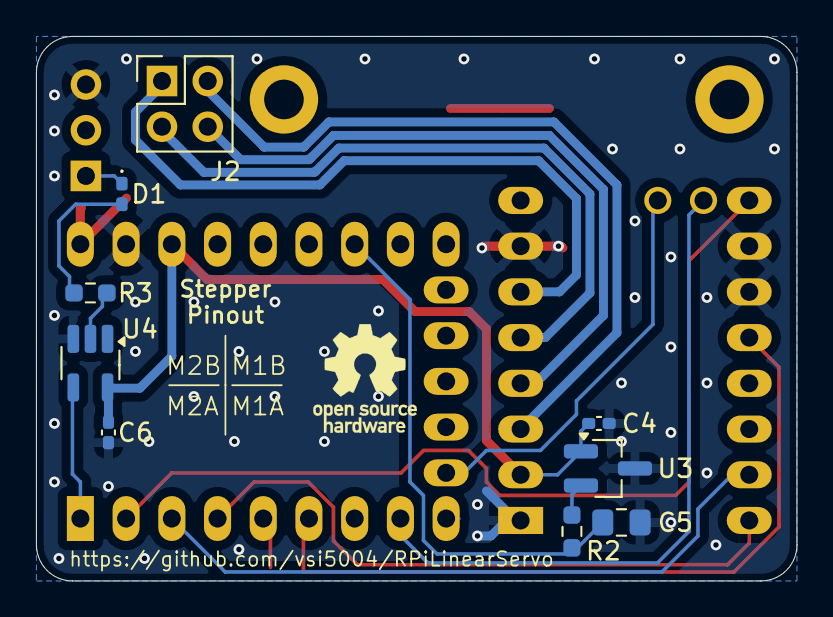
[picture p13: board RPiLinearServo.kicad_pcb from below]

Board: 2 copper layers, 42.2 x 30.2 mm, 18 parts (9 on the bottom side), 20 nets.

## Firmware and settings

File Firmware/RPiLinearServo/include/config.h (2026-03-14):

#pragma once

#include <cstdint>

// Version injected by CMake from the latest git tag (e.g. v1.0.0).
// Fallback values used only when building outside CMake.
#ifndef FW_VERSION_MAJOR
#define FW_VERSION_MAJOR 1
#endif
#ifndef FW_VERSION_MINOR
#define FW_VERSION_MINOR 0
#endif
#ifndef FW_VERSION_PATCH
#define FW_VERSION_PATCH 0
#endif
#ifndef FW_GIT_HASH
#define FW_GIT_HASH "unknown"
#endif

// Compile-time defaults.  Overridden at boot by flash-backed CONFIG.INI.

struct ServoConfig {
    float    stroke_mm         = 8.4f;
    float    deadband_mm       = 0.03f;
    float    pos_mismatch_mm   = 0.5f;
    bool     invert_stroke     = false;

    float    full_steps_per_mm = 297.6f;   // motor: ~20000 steps / 8.4mm / 8 microsteps
    bool     dir_invert        = false;

    // TMC2209 UART configuration (applied at startup via single-wire UART)
    uint16_t run_current_ma    = 100;      // RMS run current in mA
    uint16_t hold_current_ma   = 50;       // hold current in mA (motor idle)
    uint8_t  microsteps        = 8;        // 1/8 matches MS1=MS2=GND; intpol=1 interpolates to 256
    bool     stealthchop_en    = true;     // true = StealthChop (quiet), false = SpreadCycle

    uint8_t  tpowerdown       = 46;       // TPOWERDOWN register: ~1s before IRUN→IHOLD ramp

    // Derived: scales automatically with microsteps
    float steps_per_mm() const { return full_steps_per_mm * microsteps; }

    float    max_speed_mm_s    = 80.0f;    // 25,000 Hz at 583 steps/mm (matched AccelStepper)
    float    default_speed_mm_s = 40.0f;   // ~12,500 Hz CLI default
    float    min_speed_mm_s    = 0.1f;
    float    max_accel_mm_s2   = 80.0f;    // 40,000 steps/s² (matched AccelStepper)
    uint32_t auto_disable_ms   = 2000;     // disable EN after idle (0 = never)

    bool     homing_enable     = true;
    bool     home_dir_negative = true;      // true = home toward negative
    float    home_speed_mm_s   = 10.7f;    // ~half of default move speed
    float    backoff_mm        = 0.2f;
    float    home_margin       = 1.1f;      // drive 110% of stroke into hardstop
    float    zero_offset_mm    = 0.0f;

    uint32_t pwm_min_us        = 1000;
    uint32_t pwm_max_us        = 2000;
    uint32_t pwm_timeout_ms    = 100;
    bool     pwm_zero_disables = true;
    uint32_t pwm_valid_margin  = 150;

    /// Map a validated pulse width (µs) to a position in [0, stroke_mm].
    float pwm_to_mm(uint32_t pulse_us) const {
        if (pulse_us <= pwm_min_us) return 0.0f;
        if (pulse_us >= pwm_max_us) return stroke_mm;
        return (float)(pulse_us - pwm_min_us) * stroke_mm
               / (float)(pwm_max_us - pwm_min_us);
    }

    bool     led_dark_mode      = false;   // true = LED stays off at all times

    bool     sleep_when_idle     = false;   // true = enter dormant mode when PWM lost and USB not mounted

    bool     use_hall_effect     = false;   // true = use magnetic encoder feedback

    float    adc_filter_alpha   = 1.0f;   // 1.0 = no filtering (64× oversample is sufficient)
    float    lost_step_threshold_mv = 30.0f;  // mV deviation to trigger stall fault

    uint32_t min_save_interval_s = 30;     // throttle: min seconds between flash writes

    // Derived convenience: speed in Hz = speed_mm_s * steps_per_mm()
    uint32_t default_speed_hz() const {
        return static_cast<uint32_t>(default_speed_mm_s * steps_per_mm());
    }
    uint32_t min_speed_hz() const {
        return static_cast<uint32_t>(min_speed_mm_s * steps_per_mm());
    }
    uint32_t max_speed_hz() const {
        return static_cast<uint32_t>(max_speed_mm_s * steps_per_mm());
    }
    uint32_t home_speed_hz() const {
        return static_cast<uint32_t>(home_speed_mm_s * steps_per_mm());
    }
    uint32_t accel_hz_per_s() const {
        return static_cast<uint32_t>(max_accel_mm_s2 * steps_per_mm());
    }
    int32_t  backoff_steps() const {
        return static_cast<int32_t>(backoff_mm * steps_per_mm());
    }
    int32_t  stroke_steps() const {
        return static_cast<int32_t>(stroke_mm * steps_per_mm());
    }
};

// Global config instance (compile-time defaults)
inline ServoConfig g_config;

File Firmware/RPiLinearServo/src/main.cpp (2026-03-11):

#include "pins.h"
#include "config.h"
#include "stepgen.h"
#include "homing.h"
#include "cli.h"
#include "position_store.h"
#include "tmc2209.h"
#include "pwm_input.h"
#include "status_led.h"
#include "usb_stdio.h"
#include "msc_disk.h"
#include "config_store.h"
#include "hall_sensor.h"
#include "servo_loop.h"

#include "pico/stdlib.h"
#include "hardware/gpio.h"
#include "hardware/clocks.h"
#include <cstdio>
#include <cmath>


static void print_banner() {
    printf("\n");
    printf("════════════════════════════════════════════\n");
    printf("  RPiLinearServo  v%d.%d.%d (%s)\n",
           FW_VERSION_MAJOR, FW_VERSION_MINOR, FW_VERSION_PATCH, FW_GIT_HASH);
    printf("════════════════════════════════════════════\n");
    printf("  sys_clk  : %lu MHz\n",
           (unsigned long)(clock_get_hz(clk_sys) / 1000000));
    printf("  STEP=GP%d  DIR=GP%d  EN=GP%d\n", PIN_STEP, PIN_DIR, PIN_EN);
    printf("  UART_TX=GP%d (via R1)  UART_RX=GP%d\n",
           PIN_UART_TX, PIN_UART_RX);
    printf("  PWM_IN=GP%d  range=%lu–%lu µs\n",
           PIN_PWM_IN, (unsigned long)g_config.pwm_min_us,
           (unsigned long)g_config.pwm_max_us);
    printf("  steps/mm=%.0f  stroke=%.1f mm  microsteps=%u\n",
           g_config.steps_per_mm(), g_config.stroke_mm, g_config.microsteps);
    printf("  homing: hardstop (%.0f%% of stroke)\n",
           g_config.home_margin * 100.0f);
    printf("  Type 'help' for commands.\n");
    printf("════════════════════════════════════════════\n\n");
}


int main() {

    usb_stdio_init();

    gpio_init(PIN_EN);
    gpio_set_dir(PIN_EN, GPIO_OUT);
    gpio_put(PIN_EN, EN_DISABLE);

    status_led_init(PIN_LED);
    config_load(g_config);
    tmc2209_init(PIN_UART_TX, PIN_UART_RX);
    tmc2209_configure(g_config);
    stepgen_init(PIN_STEP, PIN_DIR);
    pwm_input_init(PIN_PWM_IN);

    PositionState pos;
    if (position_load(pos)) {
        g_homed = pos.homed;
        if (g_homed) {
            stepgen_set_position(pos.position_steps);
        }
    }

    hall_sensor_init();
    if (hall_sensor_enabled()) {
        hall_cal_load();
    }

    msc_disk_init();
    cli_init();
    servo_loop_init();

    bool banner_printed = false;

    while (true) {
        cli_poll();

        if (!banner_printed && usb_stdio_connected()) {
            print_banner();
            if (g_homed) {
                printf("[pos] restored homed=%d  pos=%ld steps\n",
                       g_homed, (long)stepgen_get_position());
            }
            banner_printed = true;
        }

        // Apply config changes from USB mass storage
        if (msc_disk_poll()) {
            tmc2209_configure(g_config);
        }

        // PWM tracking, post-move verification, auto-disable, hall logging
        servo_loop_poll();
        status_led_update();

        if (!stepgen_is_busy()) {
            position_save_if_needed(stepgen_get_position(), g_homed);
        }

        tight_loop_contents();
    }

    return 0;  // unreachable
}

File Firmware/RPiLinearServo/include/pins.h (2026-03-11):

#pragma once

// TMC2209 SilentStepStick stepper driver (STEP/DIR interface)
constexpr int PIN_EN      = 1;   // GP1 — nENABLE output (active-low)
constexpr int PIN_STEP    = 2;   // GP2 — STEP output (PIO-driven)
constexpr int PIN_DIR     = 3;   // GP3 — DIR output

// nENABLE is active-low on all TMC2209 boards
static constexpr bool EN_ENABLE  = false;
static constexpr bool EN_DISABLE = true;

// TMC2209 UART — half-duplex, 1K series resistor R1 on PCB between TX and bus
// GP4/GP5 are also RP2040 UART1 TX/RX — PIO UART used for flexibility
constexpr int PIN_UART_TX = 4;   // GP4 — UART TX to TMC2209 PDN/UART (via R1)
constexpr int PIN_UART_RX = 5;   // GP5 — UART RX loopback from same bus

// TMC2209 diagnostic / StallGuard output
constexpr int PIN_DIAG    = 9;   // GP9 — DIAG output from TMC2209 (high = stall) [swapped with INDEX]

// TMC2209 INDEX output (position reference — future use)
constexpr int PIN_INDEX   = 7;   // GP7 — INDEX pulse output from TMC2209 [swapped with DIAG]

// Sensors and control inputs
constexpr int PIN_PWM_IN  = 0;   // GP0 — RC PWM servo input
constexpr int PIN_HALL    = 26;  // GP26 — Hall effect sensor analog output (ADC0)

// On-board LED (RP2040-Zero uses GP16 for WS2812 RGB LED)
constexpr int PIN_LED     = 16;  // GP16 — WS2812 LED data (used as simple GPIO here)

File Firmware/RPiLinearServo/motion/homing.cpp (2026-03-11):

// Hardstop homing: drives into the mechanical end-stop for longer than
// the full stroke (home_margin × stroke), then backs off and zeros.
// When the hall sensor is enabled, stall is detected early by monitoring
// the voltage derivative (ΔmV → 0 when the motor stops moving).

#include "homing.h"
#include "stepgen.h"
#include "config.h"
#include "pins.h"
#include "status_led.h"
#include "position_store.h"
#include "hall_sensor.h"

#include "hardware/gpio.h"
#include "pico/stdlib.h"
#include <cstdio>
#include <cmath>

bool g_homed = false;bool g_stall_fault = false;
static constexpr float  STALL_THRESH_MV    = 0.8f;   // |Δfiltered| below this = no motion
static constexpr int    STALL_COUNT_NEEDED = 5;      // consecutive samples (~20 ms at 250 Hz)
static constexpr float  MIN_TRAVEL_FRAC    = 0.20f;   // ignore stall until 20% of home_steps done
static constexpr float  STALL_MIN_RANGE_MV = 15.0f;   // require this much peak-to-peak before trusting stall

bool homing_run() {
    printf("[homing] hardstop homing (margin=%.0f%%)\n",
           g_config.home_margin * 100.0f);
    status_led_set(LedStatus::HOMING);

    gpio_put(PIN_EN, EN_ENABLE);
    sleep_ms(50);


    int32_t  home_steps = static_cast<int32_t>(
                              g_config.stroke_mm * g_config.home_margin
                              * g_config.steps_per_mm());
    uint32_t home_hz    = g_config.home_speed_hz();
    uint32_t accel       = g_config.accel_hz_per_s();

    int32_t signed_steps = g_config.home_dir_negative ? -home_steps : home_steps;

    printf("[homing] driving %ld steps @ %lu Hz toward hardstop\n",
           (long)home_steps, (unsigned long)home_hz);

    stepgen_move_accel(signed_steps, home_hz, accel);

    bool hall_active = hall_sensor_enabled();
    int  stall_count = 0;
    float prev_filt  = 0.0f;
    float hall_min   = 1e9f;   // track range seen during homing
    float hall_max   = -1e9f;
    int32_t min_steps_for_stall = static_cast<int32_t>(home_steps * MIN_TRAVEL_FRAC);
    absolute_time_t next_sample = get_absolute_time();

    if (hall_active) {
        // Prime the filter with a few readings
        for (int i = 0; i < 5; i++) {
            hall_sensor_update();
            sleep_ms(4);
        }
        prev_filt = hall_sensor_filtered_mv();
        printf("[homing] hall stall detection active (threshold=%.1f mV, count=%d, min_range=%.0f mV)\n",
               (double)STALL_THRESH_MV, STALL_COUNT_NEEDED, (double)STALL_MIN_RANGE_MV);
    }

    int home_log_div = 0;          // print every 16th sample (~64 ms)
    while (stepgen_is_busy()) {
        status_led_update();

        if (hall_active
            && absolute_time_diff_us(next_sample, get_absolute_time()) >= 0) {
            hall_sensor_update();
            float cur_filt = hall_sensor_filtered_mv();
            float delta    = fabsf(cur_filt - prev_filt);
            prev_filt      = cur_filt;
            next_sample    = make_timeout_time_ms(4);  // 250 Hz

            // Track observed hall range
            if (cur_filt < hall_min) hall_min = cur_filt;
            if (cur_filt > hall_max) hall_max = cur_filt;
            float hall_range = hall_max - hall_min;

            if ((home_log_div++ & 15) == 0) {
                printf("  home  pos=%ld  raw=%u  filt=%.1f  Δ=%.2f  range=%.1f\n",
                       (long)stepgen_get_position(),
                       hall_sensor_read_mv(),
                       (double)cur_filt, (double)delta,
                       (double)hall_range);
            }

            // Only check stall after minimum travel AND enough hall
            // variation to prove we're in the active sensing region.
            //
            // Exception: if we've traveled more than a full stroke with
            // near-zero hall variation, the motor MUST be stalled — a real
            // stroke traversal would always cross the active sensing zone.
            int32_t traveled = abs(stepgen_get_position());
            int32_t stroke_steps = g_config.stroke_steps();
            bool in_active_zone = (hall_range >= STALL_MIN_RANGE_MV);
            bool flat_beyond_stroke = (!in_active_zone
                                       && traveled >= stroke_steps);

            if (traveled >= min_steps_for_stall
                && (in_active_zone || flat_beyond_stroke)) {
                if (delta < STALL_THRESH_MV) {
                    stall_count++;
                    if (stall_count >= STALL_COUNT_NEEDED) {
                        printf("[homing] hall stall detected at step %ld "
                               "(Δ < %.1f mV × %d)  adc=%u mV  filt=%.1f  "
                               "range=%.1f%s\n",
                               (long)stepgen_get_position(),
                               (double)STALL_THRESH_MV, STALL_COUNT_NEEDED,
                               hall_sensor_read_mv(),
                               (double)cur_filt,
                               (double)hall_range,
                               flat_beyond_stroke
                                   ? "  (flat>stroke — forced)"
                                   : "");
                        stepgen_stop();
                        break;
                    }
                } else {
                    stall_count = 0;
                }
            }
        } else if (!hall_active) {
            sleep_ms(10);
        }
    }

    if (hall_active && (hall_max - hall_min) < STALL_MIN_RANGE_MV) {
        printf("[homing] WARNING: hall range %.1f mV too small — stall detection "
               "was not trusted (flat sensing region). Ran full distance.\n",
               (double)(hall_max - hall_min));
    }

    printf("[homing] stall phase complete, counter = %ld\n",
           (long)stepgen_get_position());

    int32_t backoff        = g_config.backoff_steps();
    int32_t backoff_signed = g_config.home_dir_negative ? backoff : -backoff;
    printf("[homing] backing off %ld steps\n", (long)backoff);

    stepgen_move_accel(backoff_signed, home_hz, accel);
    while (stepgen_is_busy()) {
        status_led_update();
        sleep_ms(10);
    }

    stepgen_reset_position();
    g_homed = true;
    printf("[homing] homed OK — position reset to 0\n");


    if (hall_sensor_enabled()) {
        // Let motor and filter settle after stall + backoff
        printf("[homing] settling before calibration...\n");
        for (int i = 0; i < 50; i++) {   // 200 ms, 50 × 4 ms
            hall_sensor_update();
            sleep_ms(4);
        }

        printf("[homing] starting hall calibration sweep...\n");
        hall_cal_clear();

        int32_t  stroke = g_config.stroke_steps();
        uint32_t cal_hz = g_config.home_speed_hz() / 4;  // ¼ homing speed for accuracy
        if (cal_hz < 500) cal_hz = 500;
        int32_t  sample_interval = stroke / (HALL_CAL_MAX_ENTRIES - 2);
        if (sample_interval < 1) sample_interval = 1;
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

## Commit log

2026-03-08 Stage 1: PIO stepper, TMC2209 UART, hardstop homing, trapezoidal accel
    Firmware for RP2040-Zero + TMC2209 SilentStepStick linear servo:
    - PIO step pulse generation with IRQ-counted position tracking
    - Trapezoidal acceleration/deceleration via 1 kHz timer
    - TMC2209 single-wire UART config (current, microstepping, StealthChop)
    - Hardstop homing (110% stroke into end-stop, back off, zero)
    - WS2812 RGB status LED with breathing animation
    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
    [Actuator Horn.3mf, Base - Horizontal Left.3mf, Base - Vertical (Long Screws).3mf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]
2026-03-08 Stage 1+: PWM input, NVM persistence, LED idle heartbeat
    PWM input capture via PIO1/SM1 (16 ns resolution, 1000-2000 us range).
    Auto-home on first valid PWM pulse, continuous position tracking.
    PWM timeout disables motor and enters idle state.
    NVM dual-slot A/B flash storage with CRC32 validation and sequence
    counter. Homed flag and position restored on boot. Throttled saves
    (30 s min interval) to protect flash endurance.
    LED states: amber heartbeat (idle/waiting), green (holding), blue
    (moving), breathing blue (homing), red (error). Dark mode option
    added to config for future INI file support.
    New CLI commands: pwm (show PWM status), nvm (show/save/clear).
    Removed LED debug printf messag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
    [cli.cpp, config.h, homing.cpp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]
2026-03-10 Add ESD protection on pwm input, fix wrapping bug in nvm storage logic
    [RPiLinearServo-BOM.csv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]
2026-03-10 Stage 2: USB MSC config drive with composite CDC+MSC
    - Composite USB device: CDC serial + MSC virtual FAT12 drive
    - CONFIG.INI on LINEARSERVO drive for runtime parameter editing
    - STATUS.TXT shows firmware version and last config apply result
    - INI parser with section/key matching, type validation, range checks
    - Flash-backed config persistence at 0x1F2000 (CRC32 validated)
    - 10 user-editable fields: stroke, direction, current, speed, accel,
    auto-disable, PWM range, LED dark mode
    - Write-idle detection triggers parse/apply/save within 500ms
    - Custom TinyUSB CDC stdio bridge replaces pico_stdio_usb
    - Updated README with USB Config Drive documentation
    [config_ini.cpp, config_store.cpp, main.cpp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]
2026-03-11 Refactor firmware, update PCB schematic, and add per-directory READMEs
    Firmware:
    - Add hall sensor driver, servo loop, hall verification, and position store
    - Move config/NVM storage to storage/ directory, add CRC32
    - Add status LED UI module, flash map header
    - Refactor stepgen, PWM input, TMC2209 driver, WS2812, homing, CLI
    - Add composite USB (CDC+MSC) with virtual FAT12 config drive
    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
    [RPiLinearServo.kicad_sch]
2026-03-11 Add dormant sleep, release pipeline, and MIT license
    Dormant sleep mode:
    - XOSC dormant with GPIO wake on GP0 rising edge (~13 mA)
    - Forced position save pre-sleep, RAM-based restore on wake
    - 5-second boot grace period for never-had-PWM entry path
    - Safe peripheral re-init (stepgen timer/IRQ teardown, USB stdio cleanup)
    - sleep_when_idle config field persisted in flash (CFG_VERSION 5)
    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
2026-03-14 Refactor servo loop as explicit state machine, unify CLI/PWM API
    - Rewrite servo_loop.cpp as a 4-state machine (IDLE/HOMING/MOVING/HOLDING)
    with a single enter_state() controlling EN pin and LED
    - Add servo_loop_move/run/stop/enable/disable/home API; CLI commands now
    go through the same code path as PWM-driven moves
    - Fix LED stuck green after long PWM moves (MOVING -> IDLE when PWM already
    lost instead of lingering in HOLDING)
    - Fix stepper driver disabled mid-move on PWM timeout (guard with
    stepgen_is_busy)
    - Widen PWM valid margin from 50 to 150 us for signals slightly outside
    the 1000-2000 us window
    - Add PWM validity expiry in pwm_input_poll when PIO FIFO is empty
    - Remove ram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
    [Base - Horizontal Left.3mf]
2026-03-17 Update Layout and BOM with minor routing and footprint changes for PWM input voltage protection
    [RPiLinearServo-BOM.csv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]
